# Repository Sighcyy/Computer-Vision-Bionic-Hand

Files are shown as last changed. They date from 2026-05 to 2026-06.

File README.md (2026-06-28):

# Computer Vision Bionic Hand

A real-time bionic hand that mimics your finger movements using computer vision. The mechanical hand is fully 3D printed with a tendon-driven finger system, actuated by 5 SG90 servos and controlled by an ESP32 that receives live finger angles from a MediaPipe hand tracker running on a PC.



---

## How It Works

The hand is built around a **tendon-and-return mechanism** — the same principle used in real prosthetic hands. Fishing line runs from each servo horn, through guides along the finger, and anchors at the fingertip. When a servo rotates, it pulls the tendon and curls the finger. Rubber bands on the dorsal (back) side act as passive return springs, extending the finger when the servo releases tension.

On the sensing side, a Python script on your PC uses MediaPipe to track 21 landmarks on your hand in real time. For each finger it computes a curl angle from the ratio of joint distances, then streams all 5 angles to the ESP32 over USB serial at up to 30 Hz. The ESP32 converts each angle to a PWM duty cycle and drives the corresponding servo instantly.

---

## Repository Structure

```
Computer-Vision-Bionic-Hand/
├── CAD/                  # SolidWorks / STL files for all printed parts
├── Electronics/          # Schematic and wiring diagram
├── Software/
│   ├── hand_tracker.py   # PC-side: camera, MediaPipe, serial output
│   └── esp32_servo.py    # ESP32-side: serial input, servo PWM control
├── BOM.csv               # Full bill of materials with links
├── References.md         # Finger dimension sources and design notes
└── README.md
```

---

## Mechanical Design

### Finger Architecture

Each finger is made of three printed phalanx segments (fingertip, middle, and base) connected by pin joints. The joints use 2.5 mm stainless steel rod sections as axles, pressed through 2.7 mm clearance holes in the hinge ears. This gives smooth, low-friction rotation while keeping the joint tight enough to hold position under load.

<!-- [INSERT CAD RENDER OR EXPLODED VIEW HERE] -->

| Segment | Length x Width x Depth |
|---|---|
| Fingertip phalanx | 21.8 mm x 14.7 mm x 16.0 mm |
| Middle phalanx | 26.7 mm x 14.7 mm x 16.0 mm |
| Base phalanx | 30.0 mm x 14.7 mm x 16.0 mm |
| Palm | 120.0 mm x 80.0 mm x 40.0 mm |

Fillets are 7 mm on the bottom face and 5 mm on the top to reduce stress concentrations at the joint roots and improve print layer adhesion in those areas.

### Tendon Routing

Clear fishing line is used as the tendon for each finger. It runs from a small anchor point on the servo horn, along the palmar (front) face of the finger through printed routing guides, and ties off at the distal phalanx. Keeping the line close to the bone centerline minimizes lateral forces on the joints during actuation.

### Return Mechanism

Rubber bands are stretched across the dorsal (back) side of each finger between the fingertip and the base phalanx. They provide passive extension — when the servo releases tension on the tendon, the rubber band pulls the finger back to its open position. Band tension needs to be matched to servo torque; too tight and the servo struggles to close, too loose and the finger won't fully extend.

### 3D Printing Notes

All parts are printed in PLA. Recommended settings:

| Setting | Value |
|---|---|
| Layer height | 0.2 mm |
| Infill | 40% or higher for phalanges |
| Supports | Required for hinge ears and palm servo mounts |
| Material | PLA 1.75 mm |

Print the phalanges with the hinge ears oriented vertically to maximize layer strength across the joint pin holes.

---

## Electronics

### Bill of Materials

Full cost breakdown is in [`BOM.csv`](BOM.csv). Total build cost: **$62.73**

| Component | Vendor | Cost | Link |
|---|---|---|---|
| ESP32-WROOM-32 | Amazon | $16.79 | [Buy](https://www.amazon.com/ESP-WROOM-32-Development-Microcontroller-Integrated-Compatible/dp/B08D5ZD528) |
| SG90 Micro Servo Motor (x5) | Amazon | $7.99 | [Buy](https://www.amazon.com/Dorhea-Arduino-Helicopter-Airplane-Walking/dp/B07Q6JGWNV) |
| MB102 Breadboard Power Supply Module | Amazon | $8.99 | [Buy](https://www.amazon.com/ALAMSCN-Solderless-Breadboard-Battery-Arduino/dp/B08JYPMCZY) |
| PLA 1.75mm 3D Printer Filament | Amazon | $9.99 | [Buy](https://www.amazon.com/Filament-Dimensional-Accuracy-Clogging-Cardboard/dp/B0DCJR8JTG) |
| 304 Stainless Steel Round Rods (5 pcs) | Amazon | $6.99 | [Buy](https://www.amazon.com/MECCANIXITY-Stainless-Steel-Round-Various/dp/B0CZRWNXJ1) |
| Rubber Bands (assorted) | Amazon | $7.99 | [Buy](https://www.amazon.com/Rubber-Assorted-Elastic-Tactical-supplies/dp/B0DNZ8GTGF) |
| Clear Fishing Line | Amazon | $3.99 | [Buy](https://www.amazon.com/Switches-Mechanical-Keyboards-Mounted-MX1AE1NN/dp/B09ZST8WMF) |

### Power Supply

The MB102 breadboard power supply module is critical to stable servo operation. Five SG90 servos can draw over 500 mA combined when under load — well beyond what the ESP32's onboard regulator or a USB port alone can reliably supply. The MB102 plugs directly into the breadboard's power rails and accepts 7–12V DC input (or USB) and outputs a clean regulated 5V line.

**Before wiring anything:** set the MB102's voltage selection jumper to 5V. Leaving it at 3.3V will underpower the servos and cause erratic movement or no movement at all.

### Pin Mapping

| Servo | Finger | ESP32 GPIO |
|---|---|---|
| M1 | Thumb | 25 |
| M2 | Index | 14 |
| M3 | Middle | 19 |
| M4 | Ring | 33 |
| M5 | Pinky | 23 |

### Wiring

Each servo has three wires: the signal wire (orange) connects to the assigned ESP32 GPIO pin, the power wire (red) connects to the MB102's 5V rail, and the ground wire (brown/black) connects to the shared GND rail on the breadboard. The ESP32 ground must also connect to this same GND rail so the logic and power grounds are referenced together — without a common ground, the PWM signals will be unreliable.

---

## Software Setup

### 1. Flash MicroPython onto the ESP32

Download the latest firmware from [micropython.org](https://micropython.org/download/esp32/), then flash it:

```bash
pip install esptool
esptool.py --port COM3 erase_flash
esptool.py --port COM3 --baud 460800 write_flash -z 0x1000 esp32-firmware.bin
```

### 2. Upload the ESP32 script

```bash
pip install mpremote
mpremote connect COM3 cp Software/esp32_servo.py :main.py
```

Or use [Thonny](https://thonny.org/) — open `esp32_servo.py` and save it to the device as `main.py`.

### 3. Install PC dependencies

```bash
pip install opencv-python mediapipe pyserial
```

### 4. Run the hand tracker

```bash
python Software/hand_tracker.py --port COM3
```

Replace `COM3` with your actual port (`/dev/ttyUSB0` on Linux/Mac). Press `Q` to quit.

---

## Calibration

### Servo endpoints

If a servo pulls the tendon too far and jams the joint, or doesn't pull far enough to fully curl the finger, adjust the PWM duty cycle limits in `esp32_servo.py`:

```python
DUTY_MIN = 40    # raise this to shift the 0° endpoint up
DUTY_MAX = 115   # lower this to shift the 180° endpoint down
```

### Tendon tension

Anchor the fishing line with the finger in its natural open position and the servo at 90°. This ensures the servo has equal range in both directions and the tendon doesn't go slack or over-tension at the extremes.

### Rubber band stiffness

If the finger lags behind the servo on the return stroke, the rubber band is too loose — add a second band or use a stiffer one. If the servo struggles to close against the band, switch to a lighter band or shorten the anchor point.

---

## References

See [`References.md`](References.md) for finger dimension sources and design notes.

---

## Future Ideas

- Wireless control over WiFi using UDP to remove the USB tether
- Flex sensors on the arm for force feedback
- Stronger MG90S metal-gear servos for higher grip force
- Wrist rotation as a 6th axis
- Gesture macros to lock preset hand positions

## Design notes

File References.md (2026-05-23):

Finger Dimensions

images

Bottom Fillet = 7mm

Top Fillet = 5 mm

Format = Length (l#) x Width (t#) x Depth (w#)

Top of Finger = 21.8 mm x 14.7 mm x 16.0

Middle of Finger = 26.7 mm x 14.7 mm x 16.0 mm

Base of Finder =  30 mm x 14.7 mm x 16.0 mm

Palm = 120 mm x 80 mm x 40

Joints have a hole of 2.7 mm in diamter, however use a axel of 2.5 mm

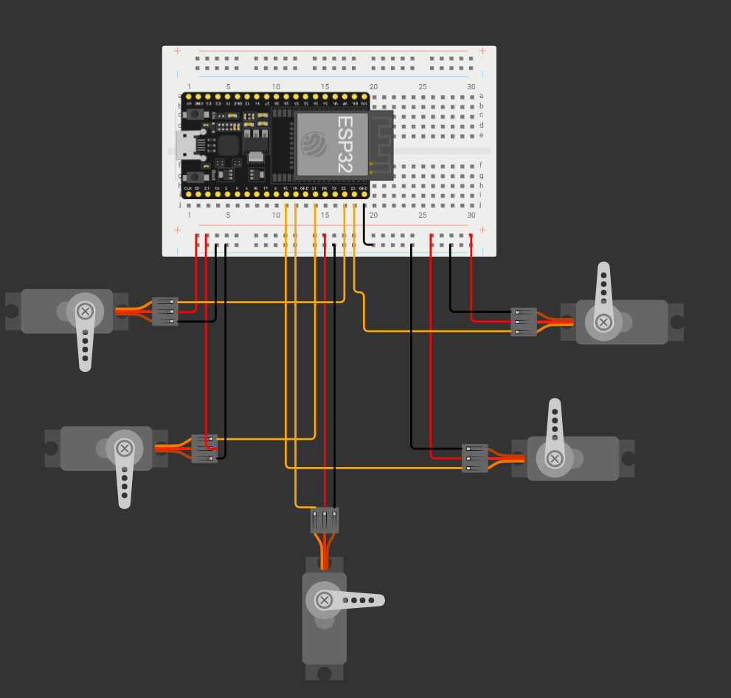
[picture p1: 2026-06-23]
Electronics/Screenshot 2026-06-23 132133.png

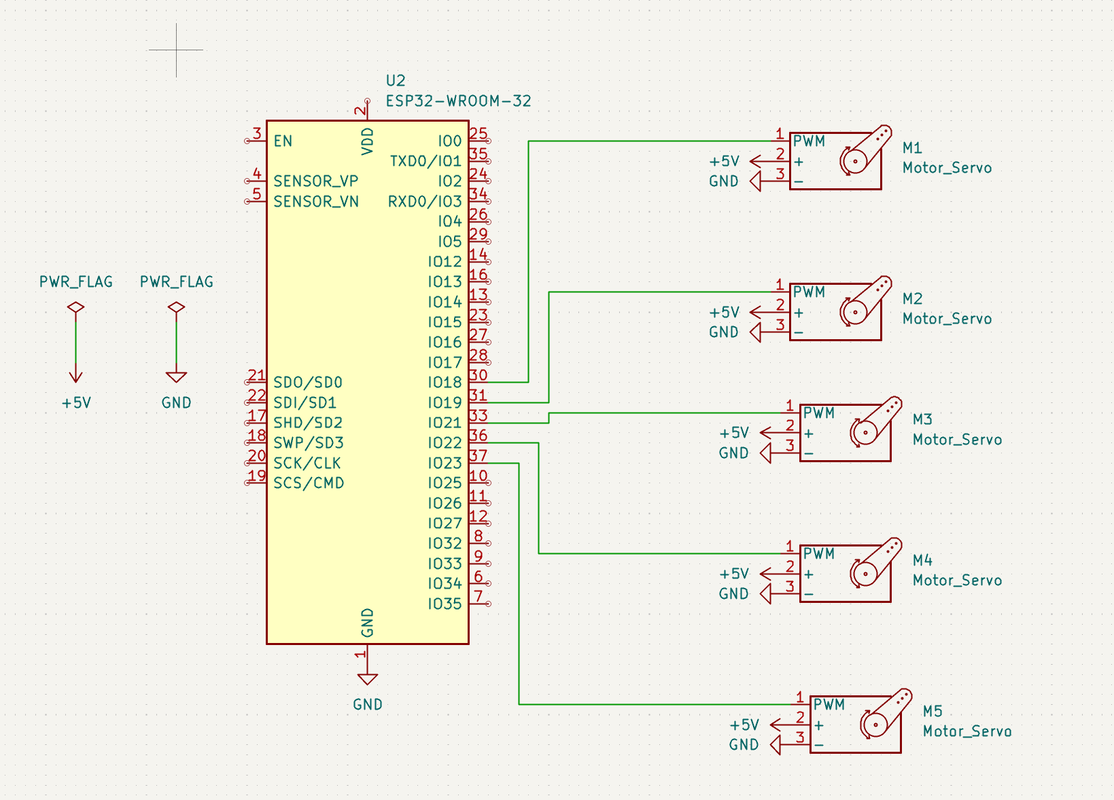
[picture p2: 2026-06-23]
Electronics/Screenshot 2026-06-23 132624.png

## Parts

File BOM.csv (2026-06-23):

Name | Vendor | Cost | Link
ESP-WROOM-32 | Amazon | $16.79 | https://www.amazon.com/ESP-WROOM-32-Development-Microcontroller-Integrated-Compatible/dp/B08D5ZD528
MECCANIXITY 5Pcs 304 Stainless Steel Round Rods Bar | Amazon | $6.99 | https://www.amazon.com/MECCANIXITY-Stainless-Steel-Round-Various/dp/B0CZRWNXJ1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
PLA 1.75mm 3D Printer Filament | Amazon | $9.99 | https://www.amazon.com/Filament-Dimensional-Accuracy-Clogging-Cardboard/dp/B0DCJR8JTG
SG90 Micro Servo Motor | Amazon | $7.99 | https://www.amazon.com/Dorhea-Arduino-Helicopter-Airplane-Walking/dp/B07Q6JGWNV
Rubber Bands | Amazon | $7.99 | https://www.amazon.com/Rubber-Assorted-Elastic-Tactical-supplies/dp/B0DNZ8GTGF?sp_csd=d2lkZ2V0TmFtZT1zcF9hdGY
Clear Fishing Line | Amazon | $3.99 | https://www.amazon.com/Switches-Mechanical-Keyboards-Mounted-MX1AE1NN/dp/B09ZST8WMF
3.3V 5V MB102 Solderless Breadboard Power Supply Module | Amazon | $8.99 | https://www.amazon.com/ALAMSCN-Solderless-Breadboard-Battery-Arduino/dp/B08JYPMCZY
___ | Total | $62.73 | _______

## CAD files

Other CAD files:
CAD/Assembly Files/Final Assembly.iam
CAD/Assembly Files/Finger Assembly.iam
CAD/Assembly Files/ThumbAssembly.iam
CAD/Individual Parts/FingerBase.ipt
CAD/Individual Parts/FingerMiddle.ipt
CAD/Individual Parts/FingerMiddleThumb.ipt
CAD/Individual Parts/FingerTop.ipt
CAD/Individual Parts/FingerTopThumb.ipt
CAD/Individual Parts/Palm.ipt

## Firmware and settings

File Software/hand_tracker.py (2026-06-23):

import cv2
import mediapipe as mp
import serial
import time
import argparse
import math

BAUD_RATE    = 115200
SEND_HZ      = 30         
SERVO_MIN    = 0          
SERVO_MAX    = 180         


FINGER_TO_SERVO = [0, 1, 2, 3, 4]   


FINGER_LANDMARKS = [
    (mp.solutions.hands.HandLandmark.THUMB_CMC,  mp.solutions.hands.HandLandmark.THUMB_TIP),
    (mp.solutions.hands.HandLandmark.INDEX_FINGER_MCP,  mp.solutions.hands.HandLandmark.INDEX_FINGER_TIP),
    (mp.solutions.hands.HandLandmark.MIDDLE_FINGER_MCP, mp.solutions.hands.HandLandmark.MIDDLE_FINGER_TIP),
    (mp.solutions.hands.HandLandmark.RING_FINGER_MCP,   mp.solutions.hands.HandLandmark.RING_FINGER_TIP),
    (mp.solutions.hands.HandLandmark.PINKY_MCP,         mp.solutions.hands.HandLandmark.PINKY_TIP),
]

FINGER_PIP = [
    mp.solutions.hands.HandLandmark.THUMB_IP,
    mp.solutions.hands.HandLandmark.INDEX_FINGER_PIP,
    mp.solutions.hands.HandLandmark.MIDDLE_FINGER_PIP,
    mp.solutions.hands.HandLandmark.RING_FINGER_PIP,
    mp.solutions.hands.HandLandmark.PINKY_PIP,
]


def dist(a, b):
    return math.sqrt((a.x - b.x)**2 + (a.y - b.y)**2 + (a.z - b.z)**2)


def finger_curl_angle(lm, mcp_id, pip_id, tip_id):
    mcp = lm[mcp_id]
    pip = lm[pip_id]
    tip = lm[tip_id]

    mcp_to_tip = dist(mcp, tip)
    mcp_to_pip = dist(mcp, pip)

    if mcp_to_pip < 1e-6:
        return 90


    ratio = mcp_to_tip / (2.0 * mcp_to_pip)
    ratio = max(0.0, min(1.0, ratio))       
    angle = int((1.0 - ratio) * SERVO_MAX)   
    return angle


def build_packet(angles):
    return "A" + ",".join(str(a) for a in angles) + "\n"

def main():
    parser = argparse.ArgumentParser()
    parser.add_argument("--port", default="COM3", help="Serial port for ESP32")
    parser.add_argument("--cam",  default=0,      type=int, help="Camera index")
    args = parser.parse_args()

    print(f"[INFO] Opening serial port {args.port} @ {BAUD_RATE} baud …")
    try:
        ser = serial.Serial(args.port, BAUD_RATE, timeout=1)
        time.sleep(2)   # let ESP32 reset
        print("[INFO] Serial connected.")
    except serial.SerialException as e:
        print(f"[ERROR] Cannot open port: {e}")
        return

    mp_hands  = mp.solutions.hands
    mp_draw   = mp.solutions.drawing_utils
    hands_det = mp_hands.Hands(
        static_image_mode=False,
        max_num_hands=1,
        min_detection_confidence=0.7,
        min_tracking_confidence=0.6,
    )

    cap = cv2.VideoCapture(args.cam)
    if not cap.isOpened():
        print("[ERROR] Cannot open camera.")
        return

    prev_time   = 0
    frame_delay = 1.0 / SEND_HZ

    print("[INFO] Running – press Q to quit.")
    while True:
        ret, frame = cap.read()
        if not ret:
            break

        frame = cv2.flip(frame, 1)
        rgb   = cv2.cvtColor(frame, cv2.COLOR_BGR2RGB)
        res   = hands_det.process(rgb)

        angles = [90, 90, 90, 90, 90] 

        if res.multi_hand_landmarks:
            lm = res.multi_hand_landmarks[0].landmark
            mp_draw.draw_landmarks(frame, res.multi_hand_landmarks[0],
                                   mp_hands.HAND_CONNECTIONS)

            for i, (mcp_id, tip_id) in enumerate(FINGER_LANDMARKS):
                pip_id = FINGER_PIP[i]
                angles[i] = finger_curl_angle(lm, mcp_id, pip_id, tip_id)

        labels = ["Thumb", "Index", "Middle", "Ring", "Pinky"]
        for i, (label, angle) in enumerate(zip(labels, angles)):
            cv2.putText(frame, f"{label}: {angle}°",
                        (10, 30 + i * 28),
                        cv2.FONT_HERSHEY_SIMPLEX, 0.7, (0, 255, 0), 2)

        cv2.imshow("Hand Tracker – Bionic Arm", frame)

   
        now = time.time()
        if now - prev_time >= frame_delay:
            packet = build_packet(angles)
            try:
                ser.write(packet.encode())
            except serial.SerialException as e:
                print(f"[WARN] Serial write error: {e}")
            prev_time = now

        if cv2.waitKey(1) & 0xFF == ord('q'):
            break

    cap.release()
    cv2.destroyAllWindows()
    ser.close()
    print("[INFO] Stopped.")


if __name__ == "__main__":
    main()

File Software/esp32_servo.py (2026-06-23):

import machine
import time
import sys

SERVO_PINS = [25, 14, 19, 33, 23]
PWM_FREQ   = 50      
DUTY_MIN   = 40        
DUTY_MAX   = 115       

servos = []
for pin_num in SERVO_PINS:
    pwm = machine.PWM(machine.Pin(pin_num), freq=PWM_FREQ)
    servos.append(pwm)

uart = machine.UART(0, baudrate=115200)


def angle_to_duty(angle):
    angle = max(0, min(180, angle))
    return int(DUTY_MIN + (angle / 180.0) * (DUTY_MAX - DUTY_MIN))


def set_servo(index, angle):
    servos[index].duty(angle_to_duty(angle))


def center_all():
    for i in range(len(servos)):
        set_servo(i, 90)


def smooth_move(targets, steps=5, delay_ms=10):
    current = [90] * 5  
    for step in range(1, steps + 1):
        for i in range(5):
            interp = int(current[i] + (targets[i] - current[i]) * step / steps)
            set_servo(i, interp)
        time.sleep_ms(delay_ms)



center_all()
print("ESP32 Bionic Arm ready. Waiting for packets…")


buf = b""

while True:
    if uart.any():
        buf += uart.read(uart.any())


        while b"\n" in buf:
            line, buf = buf.split(b"\n", 1)
            line = line.strip()

            if not line.startswith(b"A"):
                continue

            try:
                parts  = line[1:].decode().split(",")
                if len(parts) != 5:
                    continue
                angles = [int(p) for p in parts]

                # Safety clamp
                angles = [max(0, min(180, a)) for a in angles]

                for i, angle in enumerate(angles):
                    set_servo(i, angle)

            except (ValueError, UnicodeDecodeError):
                pass 

    time.sleep_ms(5)

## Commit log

2026-06-23 Add new items to BOM.csv with pricing and links
    [BOM.csv]
2026-06-23 Update BOM.csv with new costs and total
    [BOM.csv]
